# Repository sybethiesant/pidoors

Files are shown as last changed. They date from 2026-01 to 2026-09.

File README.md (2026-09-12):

# PiDoors - Open Source Access Control System






**Professional-grade physical access control powered by Raspberry Pi**

---

## Overview

PiDoors is a complete, industrial-grade access control system built on Raspberry Pi hardware. It provides enterprise-level security features while remaining affordable and open source. Designed for small businesses, makerspaces, office buildings, or anyone needing professional access control.

**Key Benefits:**
- **Cost-Effective**: 10x cheaper than commercial systems (~$100-150 per door vs $500-2000)
- **Secure**: TLS database encryption, bcrypt passwords, SQL injection protection, CSRF tokens
- **Open Source**: Full control over your security system
- **Modern Interface**: React SPA with TailwindCSS — fast, responsive single-page application
- **Offline Capable**: 24-hour local caching keeps doors working during network outages
- **Extensible**: Easy to customize and integrate

---

## Screenshots

| Dashboard | Doors |
|---|---|
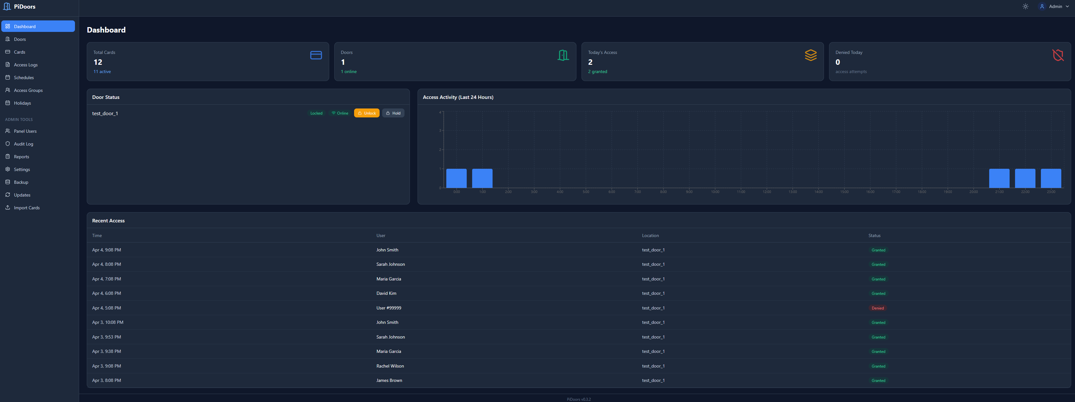
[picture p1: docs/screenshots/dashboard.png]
Dashboard
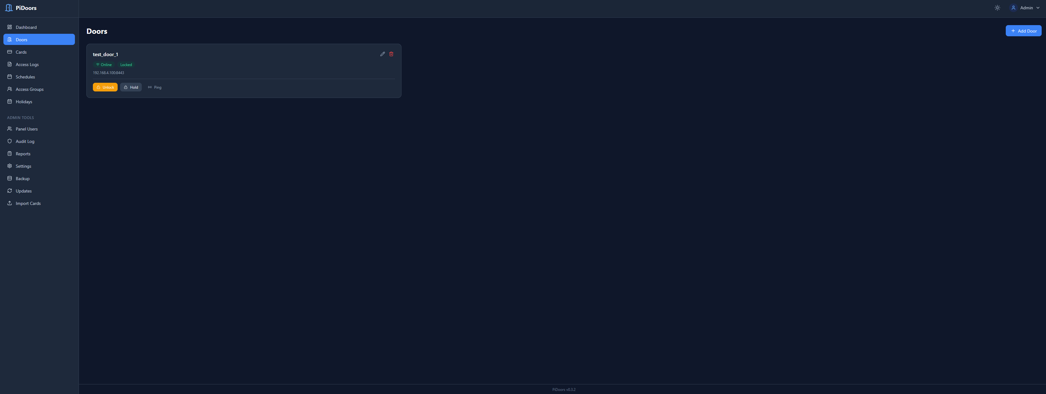
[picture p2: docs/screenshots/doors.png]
Doors
|  |  |

| Cards | Access Logs |
|---|---|
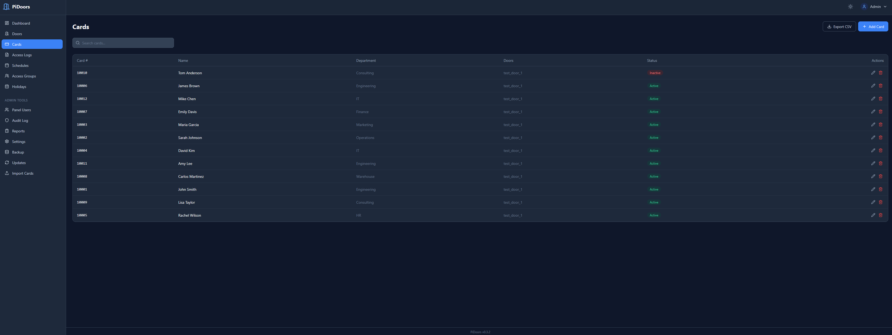
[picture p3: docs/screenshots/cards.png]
Cards
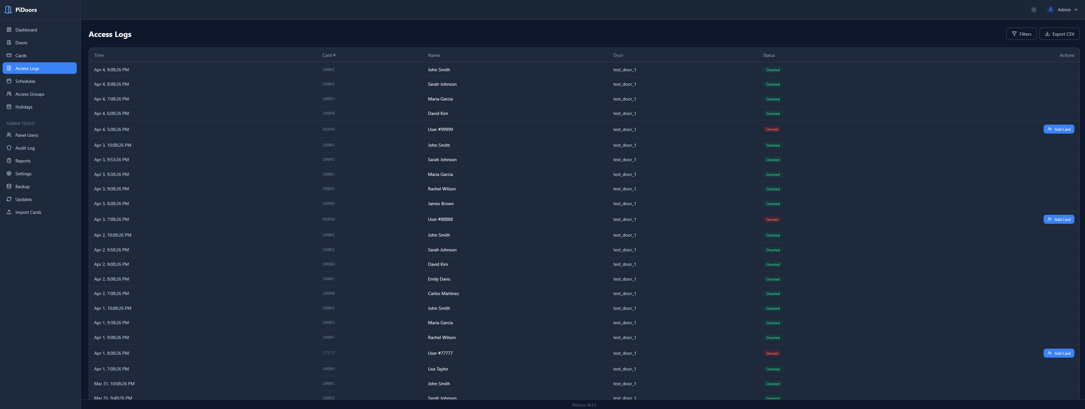
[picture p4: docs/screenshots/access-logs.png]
Access Logs
|  |  |

| Schedules | Access Groups |
|---|---|
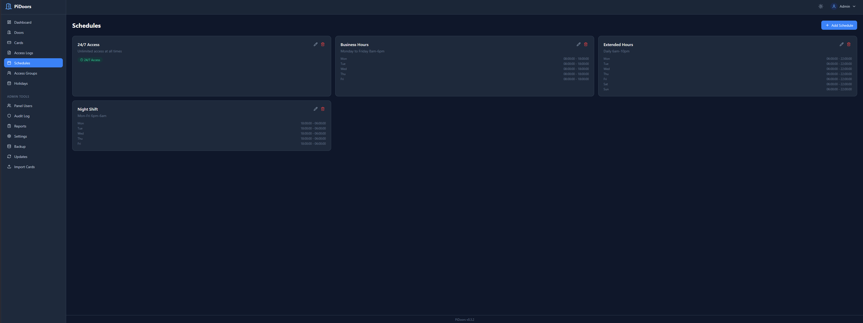
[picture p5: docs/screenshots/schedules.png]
Schedules
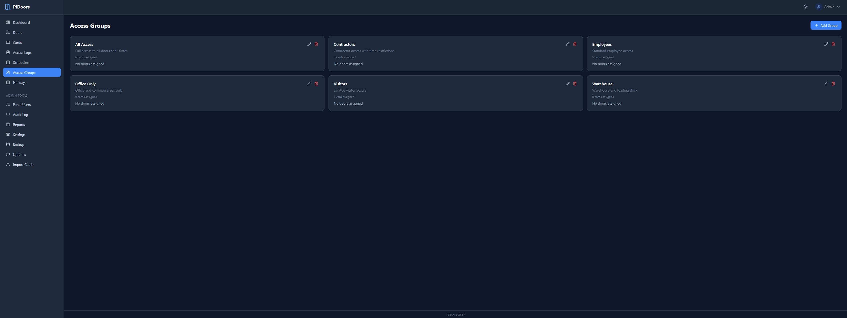
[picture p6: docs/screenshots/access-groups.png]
Access Groups
|  |  |

| Reports | Updates |
|---|---|
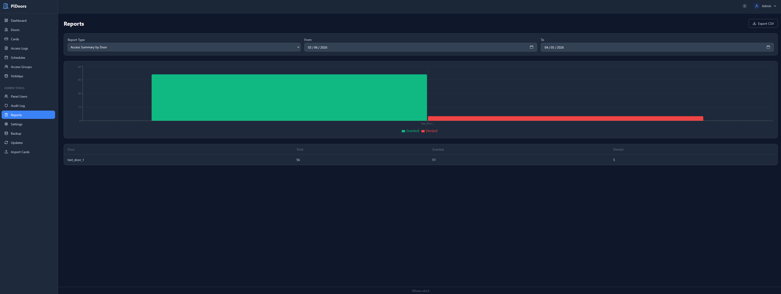
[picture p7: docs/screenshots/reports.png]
Reports
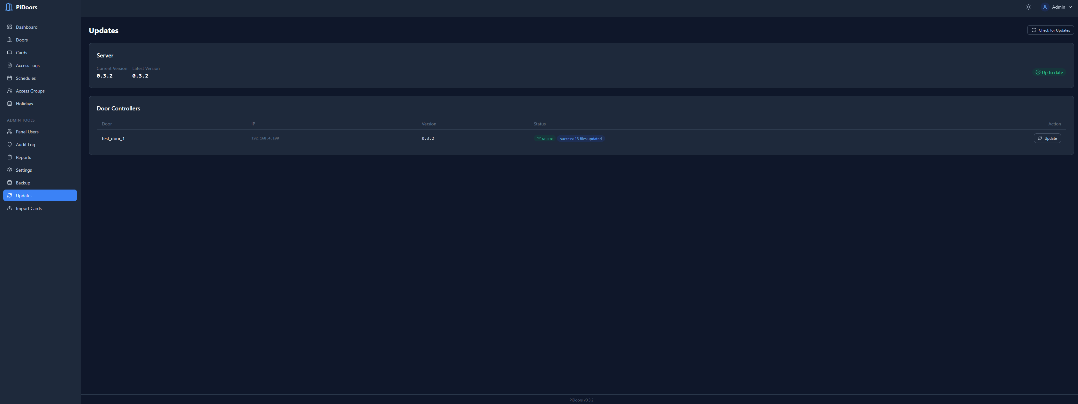
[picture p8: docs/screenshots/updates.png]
Updates
|  |  |

<details>
<summary>More screenshots</summary>

| Door Settings | Card Edit | Audit Log |
|---|---|---|
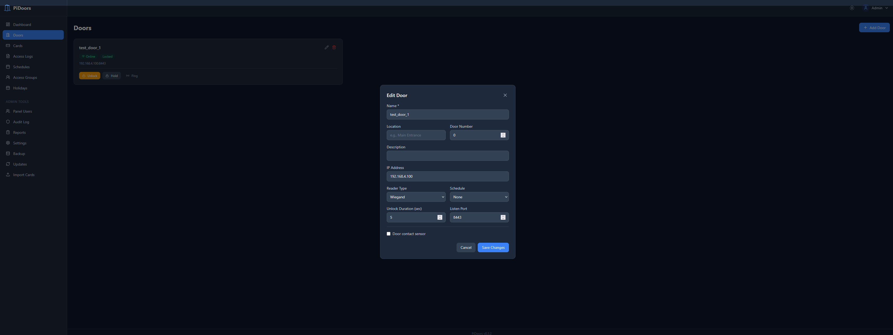
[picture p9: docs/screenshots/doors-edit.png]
Door Edit
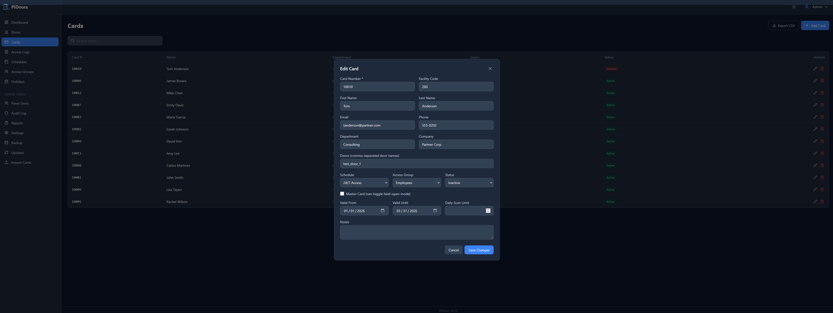
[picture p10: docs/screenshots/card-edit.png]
Card Edit
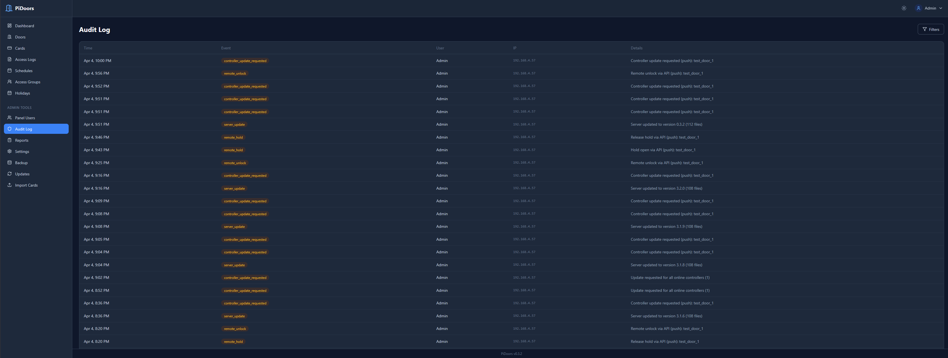
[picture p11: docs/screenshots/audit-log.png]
Audit Log
|  |  |  |

</details>

---

## Features

### Access Control
- **Multi-format Wiegand**: 26, 32, 34, 35, 36, 37, 48-bit with auto-detection
- **OSDP Readers**: RS-485 encrypted readers (planned — reader module included, not yet integrated)
- **NFC/RFID**: PN532 and MFRC522 support (planned — reader modules included, not yet integrated)
- Time-based access schedules
- Scheduled unlock — hold a door or gate open during a schedule's hours (e.g. a community gate open 6am–7pm)
- Access groups and permissions
- Holiday calendar support
- Card validity date ranges
- Persistent master cards (never expire for emergency access)
- **Master card toggle** in web UI — promote any card to master with a checkbox

### Gate Mode
- Toggle any door into **gate mode** for rolling/sliding gates with motor controllers
- 3 configurable inputs (open / stop / close physical buttons)
- 3 configurable outputs (open / stop / close relays to gate motor)
- Per-output hold duration, configurable polarity, configurable GPIO pins
- Triple-tap any button to enter hold-current-state
- Master card 3-scan = hold open (configurable)
- Stop interrupts the active output immediately
- Reverse direction commands automatically stop and reverse
- Web UI shows live gate state (idle/opening/closing/stopped/open/closed) and dedicated control buttons
- State persists across controller restarts
- Server-side pin conflict checker prevents double-assigning GPIO pins

### Reader LED
- Green / on while the door is unlocked or held open (schedule, master card or admin), red / off otherwise; a denied card blinks red
- Per-door green pin, optional red pin for bicolor readers, hi/lo polarity; defaults to the original GPIO 25 / GPIO 22 wiring
- Works on both doors and gates

### Management
- Modern React SPA with REST API backend
- Login by username or email
- Real-time dashboard with analytics
- Multi-user administration with extended profiles (name, department, company, etc.)
- Extended cardholder details (email, phone, department, employee ID, company, title)
- CSV bulk import/export with all cardholder fields (including master card flag)
- Comprehensive reporting
- Email notifications
- Complete audit trail
- Remote door control
- Instant offline detection via server-initiated polling (no stale heartbeat data)
- Door auto-registration from client heartbeat

### Updates
- One-click server updates from the web UI
- Remote controller updates via heartbeat signaling
- Pre-flight checks prevent partial updates
- Actionable error messages on failure
- Version tracking across all doors and server

### Reliability
- 24-hour offline operation
- Automatic failover
- Health monitoring
- Auto-reconnection
- Automated backups
- Service redundancy

### Security
- **TLS database encryption** — controller-to-server connections encrypted automatically
- Bcrypt password hashing (cost 12)
- PDO prepared statements (SQL injection proof)
- CSRF protection on all forms
- Secure session management
- Input validation and sanitization
- Security event logging
- Rate limiting on login

---

## Quick Start

### Prerequisites

- Raspberry Pi 3B+ or newer (Pi 4 recommended for server)
- Raspberry Pi OS (Debian-based, 64-bit recommended)
- Internet connection for initial setup
- Node.js and npm (installed automatically by `install.sh`)
- For door controllers: card reader hardware and relay module

### Automated Installation (Recommended)

```bash
# Download PiDoors
git clone https://github.com/sybethiesant/pidoors.git
cd pidoors

# Run installer as root
sudo ./install.sh
```

The installer presents three installation modes:

| Mode | Use Case |
|---|---|
| **1) Server** | Web interface + MariaDB database (run on your central Pi) |
| **2) Door Controller** | GPIO + card reader daemon (run on each door Pi) |
| **3) Full** | Both server and controller on one Pi (small deployments) |

#### What the installer does

1. Updates system packages
2. Installs dependencies (Nginx, PHP-FPM, MariaDB, Node.js, Python libraries)
3. Generates TLS certificates and enables encrypted database connections
4. Creates the `users` and `access` databases with all required tables
5. Imports the full database schema (base tables + migration extensions)
6. Deploys the PHP API to `/var/www/pidoors/`
7. Builds the React SPA and deploys to `/var/www/pidoors-ui/`
8. Configures Nginx to serve the SPA with `/api/*` routed to PHP-FPM
9. Prompts you to create an admin account (username, email + password)
10. Sets up log rotation and backup scripts

#### After installation

1. Open `https://your-pi-ip/` in a browser
2. Log in with the email (or username `Admin`) and password you set during install
3. Navigate to **Doors** to see your door controllers as they come online
4. Navigate to **Cards** to add access cards
5. Set up **Schedules** and **Access Groups** as needed

> **Installing a door controller on a separate Pi?** The server install prints a **controller enrollment token** at the end (also stored in `/var/www/pidoors/includes/config.php` as `enrollment_token`). Enter it when the door-controller install asks for it. It lets the controller obtain a CA-signed certificate so the server can push commands to it instantly; without it the controller still works, but commands fall back to database polling.

### Manual Installation

If you prefer to install manually or need to troubleshoot:

#### 1. Install system packages
```bash
sudo apt-get update && sudo apt-get install -y \
  nginx php-fpm php-mysql php-cli php-mbstring php-curl php-json \
  mariadb-server nodejs npm \
  python3 python3-pip python3-dev python3-venv git curl
```

#### 2. Create databases
```bash
sudo mysql_secure_installation

sudo mysql -u root -p <<'SQL'
CREATE DATABASE IF NOT EXISTS users;
CREATE DATABASE IF NOT EXISTS access;
CREATE USER IF NOT EXISTS 'pidoors'@'localhost' IDENTIFIED BY 'YOUR_PASSWORD';
CREATE USER IF NOT EXISTS 'pidoors'@'%' IDENTIFIED BY 'YOUR_PASSWORD';
GRANT ALL PRIVILEGES ON users.* TO 'pidoors'@'localhost';
GRANT ALL PRIVILEGES ON access.* TO 'pidoors'@'localhost';
GRANT ALL PRIVILEGES ON users.* TO 'pidoors'@'%';
GRANT ALL PRIVILEGES ON access.* TO 'pidoors'@'%';
FLUSH PRIVILEGES;
SQL
```

> **Note:** The `'pidoors'@'%'` user allows door controllers on other Pis to connect remotely. You also need to set `bind-address = 0.0.0.0` in `/etc/mysql/mariadb.conf.d/50-server.cnf` and restart MariaDB.

#### 3. Import schemas
```bash
# Create the users table and audit_logs table in the users database
sudo mysql -u root -p users <<'SQL'
CREATE TABLE IF NOT EXISTS `users` (
  `id` int(11) NOT NULL AUTO_INCREMENT,
  `user_name` varchar(100) NOT NULL,
  `user_email` varchar(255) NOT NULL,
  `user_pass` varchar(255) NOT NULL,
  `admin` tinyint(1) NOT NULL DEFAULT 0,
  `active` tinyint(1) NOT NULL DEFAULT 1,
  `created_at` datetime DEFAULT CURRENT_TIMESTAMP,
  `last_login` datetime DEFAULT NULL,
  PRIMARY KEY (`id`),
  UNIQUE KEY `user_email` (`user_email`)
) ENGINE=InnoDB DEFAULT CHARSET=utf8mb4;

CREATE TABLE IF NOT EXISTS `audit_logs` (
  `id` int(11) NOT NULL AUTO_INCREMENT,
  `event_type` varchar(50) NOT NULL,
  `user_id` int(11) DEFAULT NULL,
  `ip_address` varchar(45) DEFAULT NULL,
  `user_agent` varchar(255) DEFAULT NULL,
  `details` text,
  `created_at` datetime NOT NULL DEFAULT CURRENT_TIMESTAMP,
  PRIMARY KEY (`id`),
  KEY `event_type` (`event_type`),
  KEY `user_id` (`user_id`),
  KEY `created_at` (`created_at`)
) ENGINE=InnoDB DEFAULT CHARSET=utf8mb4;
SQL

# Import the access database schema and migration extensions
sudo mysql -u root -p access < database_migration.sql
```

The migration script creates all access tables, adds extended columns, and also switches to the `users` database to add profile columns. It is safe to re-run on existing installations.

#### 4. Create your admin user
```bash
# Generate a bcrypt hash for your password
HASH=$(php -r "echo password_hash('YOUR_PASSWORD', PASSWORD_BCRYPT);")

sudo mysql -u root -p users -e \
  "INSERT INTO users (user_name, user_email, user_pass, admin, active) \
   VALUES ('Admin', 'admin@example.com', '$HASH', 1, 1);"
```

#### 5. Deploy the PHP API
```bash
sudo mkdir -p /var/www/pidoors
sudo cp -r pidoorserv/* /var/www/pidoors/
sudo cp VERSION /var/www/pidoors/
sudo cp /var/www/pidoors/includes/config.php.example /var/www/pidoors/includes/config.php
sudo nano /var/www/pidoors/includes/config.php    # Set your database password and server IP
sudo chown -R www-data:www-data /var/www/pidoors
sudo chmod 640 /var/www/pidoors/includes/config.php
```

#### 6. Build and deploy the React SPA
```bash
sudo apt-get install -y nodejs npm
cd pidoors-ui
npm install && npm run build
sudo mkdir -p /var/www/pidoors-ui
sudo cp -r dist/* /var/www/pidoors-ui/
sudo chown -R www-data:www-data /var/www/pidoors-ui
cd ..
```

#### 7. Configure Nginx
```bash
# Detect your PHP version
PHP_VERSION=$(php -r "echo PHP_MAJOR_VERSION.'.'.PHP_MINOR_VERSION;")

# Install config with correct PHP socket path
sudo sed "s|php-fpm.sock|php${PHP_VERSION}-fpm.sock|g" \
  nginx/pidoors.conf > /etc/nginx/sites-available/pidoors
sudo ln -sf /etc/nginx/sites-available/pidoors /etc/nginx/sites-enabled/pidoors
sudo rm -f /etc/nginx/sites-enabled/default
sudo nginx -t && sudo systemctl reload nginx
```

See the [Installation Guide](pidoors/INSTALLATION_GUIDE.md) for additional details.

---

## System Architecture

```
                    REACT SPA (Browser)
     Dashboard | Cards | Doors | Logs | Reports | Settings
                          |
                     /api/* REST
                          |
     SERVER RASPBERRY PI
    +--------------------------+
    |  Nginx                   |
    |  ├─ /         → React   |
    |  └─ /api/*    → PHP-FPM |
    |  MariaDB (TLS)           |
    |  Backups & Logs          |
    +--------------------------+
          |                  |
     HTTPS Push         TLS/TCP DB
     (instant)          (sync/poll)
          |                  |
    +----------------+  +----------------+
    |  Door Pi #1    |  |  Door Pi #N    |
    |  Push Listener |  |  Push Listener |
    |  24hr Cache    |  |  24hr Cache    |
    |  Card Reader   |  |  Card Reader   |
    |  Electric Lock |  |  Electric Lock |
    +----------------+  +----------------+
```

**One server Pi** runs the React SPA, PHP API, and database.
**N door Pis** control individual access points with 24-hour local caching.
The server pushes commands instantly via HTTPS, with database polling as fallback.
The server pings controllers on each page load for instant status. Heartbeat runs every 5 minutes as a safety net.

---

## Hardware Requirements

### Server (1 per system)
| Component | Requirement |
|---|---|
| Board | Raspberry Pi 3B+ or newer (4GB RAM recommended) |
| Storage | 16GB+ microSD card |
| Network | Ethernet recommended |
| Power | Official Raspberry Pi power supply |

### Door Controller (1 per door)
| Component | Requirement |
|---|---|
| Board | Raspberry Pi Zero W or newer |
| Storage | 8GB+ microSD card |
| Reader | See supported readers below |
| Lock | 12V electric strike or magnetic lock |
| Relay | Relay module for lock control |
| Optional | Door sensor, REX button |

**Supported Card Readers:**
| Type | Interface | Notes |
|---|---|---|
| Wiegand (26/32/34/35/36/37/48-bit) | GPIO | Most common, auto-detection |
| Wiegand keypad (PIN codes) | GPIO | Burst mode or per-key (4/8-bit) mode — see *Wiegand Keypads (PIN Codes)* below |
| LCD display (HD44780) | I2C or GPIO | Optional status display at the door — see *LCD Display at the Door* below |
| OSDP v2 | RS-485 (UART) | Encrypted, requires USB-RS485 adapter — **planned, reader module not yet wired into the controller** |
| PN532 NFC | I2C or SPI | Mifare Classic, Ultralight, NTAG — **planned, reader module not yet wired into the controller** |
| MFRC522 NFC | SPI | Low-cost Mifare reader |

**Total cost per door: ~$100-150**

---

## Configuration

### Server Configuration

1. Copy the configuration template:
```bash
cp pidoorserv/includes/config.php.example pidoorserv/includes/config.php
```

2. Edit configuration:
```bash
nano pidoorserv/includes/config.php
```

3. Set your values:
```php
return [
    'sqladdr' => '127.0.0.1',
    'sqldb' => 'users',
    'sqldb2' => 'access',
    'sqluser' => 'pidoors',
    'sqlpass' => 'your_secure_password',
    'url' => 'https://your-pi-ip',
    // ... other settings
];
```

4. Secure the file:
```bash
chmod 640 pidoorserv/includes/config.php
```

### Door Controller Configuration

1. Copy the configuration template:
```bash
cp pidoors/conf/config.json.example pidoors/conf/config.json
```

2. Edit configuration:
```bash
nano pidoors/conf/config.json
```

3. Set your values (use your actual door name as the key):
```json
{
    "frontdoor": {
        "reader_type": "wiegand",
        "d0": 24,
        "d1": 23,
        "wiegand_format": "auto",
        "latch_gpio": 18,
        "open_delay": 5,
        "unlock_value": 1,
        "sqladdr": "SERVER_IP_ADDRESS",
        "sqluser": "pidoors",
        "sqlpass": "your_database_password",
        "sqldb": "access"
    }
}
```

---

## Wiring Guide

### Wiegand Reader to Raspberry Pi

**Important:** Most Wiegand readers output 5V logic signals, but Raspberry Pi GPIO pins are 3.3V only. A **bi-directional logic level shifter** (5V to 3.3V) is recommended on the DATA0 and DATA1 lines to protect the Pi's GPIO pins. Without one, the Pi may work initially but the GPIO pins can be damaged over time.

| Wiegand Reader | Level Shifter | Raspberry Pi |
|---|---|---|
| DATA0 (Green)  | HV1 → LV1 | GPIO 24 |
| DATA1 (White)  | HV2 → LV2 | GPIO 23 |
| GND (Black) | GND (shared)  | GND (Pin 6)  |
| 5V+ (Red) | HV | 5V (Pin 2) |
| — | LV | 3V3 (Pin 1)  |

### Lock Relay Control

| Relay Module | Raspberry Pi |
|---|---|
| IN | GPIO 18 |
| VCC | 5V (Pin 4) |
| GND | GND (Pin 14) |

Connect lock to relay NO/COM terminals with 12V power supply.

### Gate Mode Wiring (Optional)

For rolling/sliding gates with motor controllers, enable **Gate Mode** in the door edit page. Each gate has up to 3 inputs (physical buttons) and 3 outputs (relays to the gate motor). All inputs and outputs are optional — only enable the ones your hardware supports. GPIO pins are assigned in the web UI from the available pin list.

**Gate Outputs (relays to motor)** — typically wire each relay's NO/COM terminals to the corresponding input on your gate motor controller (open, stop, close terminals).

| Gate Output | Purpose |
|---|---|
| Open relay  | Held active for the configured duration to open the gate |
| Close relay | Held active for the configured duration to close the gate |
| Stop relay  | Optional — fires when stop is triggered, for motor controllers with a dedicated stop input |

**Gate Inputs (physical buttons or RF remote relays)** — wire the button/relay between the assigned GPIO pin and GND (default pull-up mode).

| Gate Input  | Purpose |
|---|---|
| Open button | Triggers the open output (3-tap = hold open) |
| Close button | Triggers the close output (3-tap = hold closed) |
| Stop button | Cuts the active output immediately (3-tap = hold at current position) |

**Voltage Warning:** Same as Wiegand readers — if your buttons or RF remote relays output 5V signals, use a level shifter to protect the Pi's 3.3V GPIO inputs. For dry-contact switches (relay closures to ground) no level shifter is needed.

In gate mode, the regular **Lock Relay** is unused — the gate's open/close outputs replace it. The "Unlock Duration" field in the door edit page is automatically hidden when gate mode is enabled. Each gate output has its own configurable hold duration.

### LED Feedback

The reader LED follows the state of the door, so members can see whether it is open right now:

| Door state | Green line | Red line (if wired) |
|---|---|---|
| Locked / idle | Off | On |
| Unlocked by a card, held open by a **schedule**, master card or admin, gate open cycle or gate held | On | Off |
| Card denied while locked | Off (single-line readers blink it on) | Blinks dark |
| Card denied while open | Blinks off | Blinks on (shows red) |

Configure it in the **Reader LED** section of the door edit page; changes take effect on the next config push, no restart needed.

- **LED pin (green / open)** — the line that is lit while the door is open. For readers with a single LED control input (most HID / Wiegand readers, where pulling the line low turns the LED green) this is the only pin you need; set **Active** to *Low* for those.
- **Red pin (optional)** — a second line for keypads with separate red and green inputs, or a two-wire bicolor LED. It is driven as the inverse of the green line.
- **Active** — high (3.3V) or low (GND) for both lines.

A door that has never had its LED configured uses the original wiring, GPIO 25 green and GPIO 22 red, active high, and that is what the form shows preselected. Untick **Reader LED** to stop driving those pins, which frees them for gate I/O, an LCD or a reader that needs them (the MFRC522 reset line, for example). All LED pins go through the same pin-conflict checks as everything else on the door.

### LCD Display at the Door

An optional character LCD (the common HD44780 type: 16x2, 20x4, etc.) can be attached to the controller to show what is happening at the door. Enable **LCD display** on the door edit page; the controller picks the change up on the next config push, no restart needed.

What it shows:
- **Idle**: the door name on line 1; `Ready`, `Held open`, `Gate held` or `LOCKDOWN` plus the time on line 2.
- **Access granted** with the cardholder's name, or **Access denied** with the reason, for 3 seconds.
- **Enter code** with one `*` per digit while a PIN is typed on a per-key keypad.

Two wiring types are supported. Pins are assigned in the web UI and checked against everything else on the door (reader, lock, sensor, gate I/O, status LED).

| Wiring | Config | Notes |
|---|---|---|
| **I2C backpack** (PCF8574 piggyback board, 4 wires) | Address (usually `0x27` or `0x3F`), bus (1) | Uses GPIO 2 (SDA) / GPIO 3 (SCL). Enable I2C once on the controller: `sudo raspi-config nonint do_i2c 0`, and make sure the service user can use the bus: `sudo usermod -aG i2c pidoors` (fresh installs do this for you). Find the address with `i2cdetect -y 1`. |
| **GPIO wired** (HD44780 in 4-bit mode) | RS, E, D4, D5, D6, D7, optional backlight pin | Tie RW to GND, D0–D3 unconnected, contrast pot on V0. Any free GPIO pins. |

Most 5V LCDs run happily with 3.3V logic on the data lines; power the panel from 5V. The display is best-effort: if it fails to initialise the controller logs `LCD setup failed` and carries on without it.

### Wiegand Keypads (PIN Codes)

A Wiegand keypad works with PiDoors today with no extra configuration. The controller does not distinguish a code typed on a keypad from a card presented to a reader: both arrive as a Wiegand frame, and a PIN is enrolled and managed exactly like a card. This also makes PiDoors usable for machine or equipment access (see the end of this section).

**What you need**

- Any keypad, or combined reader/keypad, with a Wiegand output. Both output modes work:
  - **Buffered / burst / "card format" mode**: the user types the digits and presses `#` (or waits for the keypad's timeout), and the keypad sends the whole code as **one** 26-bit (or 34/37-bit) frame. The controller decodes it like a card.
  - **Per-key mode** (4-bit or 8-bit "one frame per keypress"): the keypad sends each key as it is pressed. The controller collects the digits itself; `#` submits, `*` clears, and a pause of more than 5 seconds between keys discards a half-typed code. The digits are packed into the same 26-bit (or 34-bit for codes above 16,777,215) frame a burst-mode keypad would send, so a code enrolled on one kind of keypad matches on the other. Per-reader settings in `config.json`: `pin_timeout` (seconds, default 5) and `pin_max_length` (digits, default 10).
  - Most inexpensive keypads support both and default to per-key; the mode is a DIP switch or programming-code option in the keypad's manual (look for "Wiegand output format"). It no longer matters which one you pick.
- Wire DATA0 / DATA1 exactly like a card reader (see *Wiegand Reader to Raspberry Pi* above), including the 5V → 3.3V level shifter. The keypad's LED control line can go to GPIO 22 (see *LED Feedback*) so it turns green on a valid code.
- Nothing to change on the controller or in `config.json`. The frame is decoded by the same format registry (26/32/34/35/36/37/48-bit, parity checked).

**What does not work**

- **Card + PIN (two-factor).** The `pin_code` column on cards is stored, imported and exported, but the controller does not enforce it. A PIN is a standalone credential.
- **Non-Wiegand keypads**: matrix keypads on GPIO, I²C expanders such as the PCF8574, USB keypads. These would need a new reader module under `pidoors/readers/`. The `BaseReader` interface is there, but only the Wiegand reader is wired into the controller today; the OSDP and NFC modules are also not yet integrated.

**How a PIN becomes a credential**

- The keypad packs the digits into the frame's data bits. The controller validates parity, then splits the frame into *facility* + *user ID* by frame length (26-bit: 8 + 16 bits; 34-bit: 16 + 16; 37-bit: 16 + 19). A 6-digit code on a 26-bit keypad therefore usually shows up as a non-zero facility with a 5-digit user ID. That is expected: what matters is that the same code always produces the same pair.
- Code length is limited by the frame's data bits, not by a digit count: a 26-bit frame carries 24 data bits (codes up to 16,777,215, i.e. 8 digits), 34-bit carries 32. Some keypads impose their own maximum; check the manual.
- Leading zeros are not preserved: `000123` and `123` are the same credential.

**Enrolling a code**

1. Type the code on the keypad and press `#`.
2. The controller denies it as unknown, inserts it into the database as an **inactive** card, and logs the attempt (the controller must be able to reach the database for this; offline it just denies).
3. In the web UI open **Logs**, find the denied entry, and click **Set Up Card**. Give it a name, doors, group/schedule, and set it active.
4. Type the code again. Access is granted.

The same flow works for new cards, so a keypad or reader at any door doubles as an enrollment station. There is no need for a reader at the server.

**Machine / equipment access.** To gate a machine rather than a door, drive a latching relay or contactor that powers the machine from the lock relay output. Set the door's **Unlock Duration** to how long the machine should stay enabled after a valid code (up to the `max_unlock_duration` setting), use a master-card hold (3 scans) to keep it enabled indefinitely, or assign an **Unlock Schedule** to keep it powered during set hours.

### GPIO Pin Reference
```
    3V3  (1)  (2)  5V
  GPIO2  (3)  (4)  5V
  GPIO3  (5)  (6)  GND
  GPIO4  (7)  (8)  GPIO14
    GND  (9)  (10) GPIO15
 GPIO17 (11) (12) GPIO18    <- Relay (GPIO18)
 GPIO27 (13) (14) GND
 GPIO22 (15) (16) GPIO23    <- DATA1 (GPIO23)
    3V3 (17) (18) GPIO24    <- DATA0 (GPIO24)
 GPIO25 <- Green LED (legacy)
 GPIO22 <- Red LED (legacy)
```

Full wiring diagrams available in [Installation Guide](pidoors/INSTALLATION_GUIDE.md#wiring).

---

## Usage

### Adding a Card

**Via Web Interface:**
1. Navigate to **Cards** > **Add Card**
2. Enter card details (scan card at reader to get ID)
3. Assign access groups and schedules
4. Click **Add Card**

**Via a reader or keypad (auto-enrollment):**
1. Present the card (or type the PIN and press `#`) at any door. The attempt is denied and the credential is saved as an inactive card.
2. Open **Logs**, find the denied entry, click **Set Up Card**, fill in the details and set it active.

**Via CSV Import:**
```csv
card_id,user_id,firstname,lastname,email,department
12345678,EMP001,John,Smith,john@example.com,Engineering
87654321,EMP002,Jane,Doe,jane@example.com,Marketing
```

Upload at **Cards** > **Import CSV**. Optional columns: `email`, `phone`, `department`, `employee_id`, `company`, `title`, `notes`, `group_id`, `schedule_id`, `valid_from`, `valid_until`, `pin_code` (stored only; card + PIN is not enforced by the controller, see *Wiegand Keypads (PIN Codes)*).

### Creating Access Schedules

1. Go to **Schedules** > **Add Schedule**
2. Name the schedule (e.g., "Business Hours")
3. Add one or more **time windows**. Each window has a set of days (tap to toggle Mon–Sun) and a start/end time; a day can appear in as many windows as you need, and an end earlier than the start runs past midnight. For example, a gate that opens every day 11:30–13:10, Mon–Fri 16:45–18:30 and Sat–Sun 07:30–09:15 is three windows on one schedule.
4. Assign to cards (restricts when the card works) or to doors (see below)

### Access Groups

An access group carries a list of doors. A card assigned to a group is granted every door in the group's list **in addition to** the doors on the card itself, so you can manage door sets centrally and leave most cards' own door list empty. Notes:

- The group must list doors explicitly. A group with no doors selected grants nothing extra (it is just a label), and it never restricts a card's own doors.
- Schedules, validity dates, holidays and scan limits still come from the card.
- Controllers pick up group changes on their next cache sync (hourly, or immediately on a config push).

### Scheduled Unlock (Hold Open by Schedule)

To keep a door or gate open during set hours — a community gate open 6am–7pm, a lobby door unlocked during business hours — assign a schedule to the **door** in **Doors** > edit > **Unlock Schedule**.

- When the schedule window opens, the controller enters the held-open state (latch energized, or gate opened and held). When it closes, the door relocks (or the gate is released and closed).
- The controller evaluates the schedule every 15 seconds and acts on the transitions, so a master card or an admin can still release a hold mid-window; the schedule will not fight that release and re-applies on the next window start.
- A controller that reboots mid-window re-applies the hold. Clearing the door's schedule releases a hold the schedule applied.
- **Lockdown mode** and **access-denied holidays** override the schedule — a door that is locked down or closed for a holiday is never propped open.
- A schedule can have several windows a day (v0.4.9+); the door is held open during each one and relocks in the gaps between them.
- Overnight windows (e.g. 22:00 → 06:00) are supported. Master-card and admin holds placed *before* the window opens are left alone at window end.
- Card access is unaffected: outside the window the door works normally for authorized cards. Leave the door schedule at **None** for a door that should only ever open on a valid card.

### Monitoring Access

- **Dashboard**: Real-time statistics and charts
- **Access Logs**: Filter by date, door, user; export to CSV
- **Audit Log**: Track all administrative actions
- **Email Alerts**: Failed access attempts, door offline notifications

---

## Maintenance

### Automatic Backups
Backups run daily at 2 AM to `/var/backups/pidoors/` (database dumps plus the web root). Retention follows the **Backup retention (days)** value on the Settings page, default 30. The dump credentials live in the root-only file `/etc/pidoors/backup.cnf`.

### Manual Backup
```bash
sudo /usr/local/bin/pidoors-backup.sh
```

### Update PiDoors

**Via Web UI (Recommended):**
1. Go to **Updates** in the admin sidebar
2. Click **Check for Updates** to see the latest release
3. Click **Update Server** to update the web interface
4. Use the **Doors** page to push updates to door controllers

**Manual update:**
```bash
cd ~/pidoors
git pull
sudo cp -r pidoorserv/* /var/www/pidoors/
sudo systemctl restart nginx
sudo systemctl restart pidoors  # On door controllers
```

### Database Migrations

Both the in-app updater and `server-update.sh` apply `database_migration.sql` automatically through the root helper `/usr/local/sbin/pidoors-db-migrate` (v0.4.7+). If an update reports that the migration failed, fix the reported error and run:

```bash
sudo /usr/local/sbin/pidoors-db-migrate
```

If the helper is missing (installs made before v0.4.7 that have only ever updated through the web UI), run `sudo bash server-update.sh` once from the extracted release; it installs the helper and applies any missed migrations.

To run the migration by hand instead:

```bash
# Backup first
mysqldump -u pidoors -p access > backup_access_$(date +%Y%m%d).sql
mysqldump -u pidoors -p users > backup_users_$(date +%Y%m%d).sql

# Run migration (safe to re-run, uses IF NOT EXISTS checks)
mysql -u root -p access < database_migration.sql
```

The migration script handles both the `access` and `users` databases automatically.

**v2.2.1 Migration (Required if upgrading from v2.2 or earlier):**

This migration converts door assignments from space-separated to comma-separated format:

```bash
python3 migrations/migrate_doors_format.py --dry-run   # Preview
python3 migrations/migrate_doors_format.py              # Apply
```

### View Logs
```bash
# Door controller logs
sudo journalctl -u pidoors -f

# Web server logs
sudo tail -f /var/log/nginx/pidoors_error.log
```

---

## Security

### Security Features
- TLS encryption for all database connections (auto-configured during install)
- Bcrypt password hashing with automatic MD5 upgrade
- PDO prepared statements (no SQL injection)
- CSRF token protection on all forms
- Secure session handling with timeout
- Comprehensive input validation
- Complete audit logging
- Login rate limiting (5 attempts, 15-minute lockout)

### Reporting Vulnerabilities
Please report security issues to the repository owner directly, not via public issues.

---

## File Structure

```
pidoors/
├── pidoorserv/           # PHP API backend
│   ├── api.php           # Unified REST API router
│   ├── includes/         # Core PHP includes
│   │   ├── config.php.example
│   │   ├── security.php
│   │   ├── header.php
│   │   ├── push.php      # Push communication & status polling
│   │   ├── notifications.php
│   │   └── smtp.php      # Lightweight SMTP sender
│   ├── cron/             # Scheduled tasks (notifications)
│   ├── users/            # User management
│   ├── database/         # Database connection
│   ├── css/              # Stylesheets (legacy)
│   └── js/               # JavaScript (legacy)
├── pidoors-ui/           # React SPA frontend
│   ├── src/
│   │   ├── pages/        # Dashboard, Cards, Doors, Settings, etc.
│   │   ├── components/   # Shared UI components
│   │   ├── contexts/     # Auth context
│   │   ├── api/          # REST API client
│   │   └── types/        # TypeScript type definitions
│   ├── package.json
│   └── vite.config.ts
├── pidoors/              # Door controller
│   ├── pidoors.py        # Main daemon
│   ├── pidoors.service   # Systemd service
│   ├── pidoors-update.sh # Self-update script (runs as root via sudo)
│   ├── readers/          # Card reader modules
│   │   ├── base.py       # Abstract base class
│   │   ├── wiegand.py    # Wiegand GPIO reader
│   │   ├── osdp.py       # OSDP RS-485 reader
│   │   ├── nfc_pn532.py  # PN532 NFC reader
│   │   └── nfc_mfrc522.py # MFRC522 NFC reader
│   ├── formats/          # Card format definitions
│   │   └── wiegand_formats.py
│   └── conf/             # Configuration
│       └── config.json.example
├── nginx/                # Nginx configuration
│   └── pidoors.conf
├── docker/               # Docker dev/test environment
│   ├── docker-compose.yml
│   ├── Dockerfile.server
│   ├── Dockerfile.door
│   ├── server-entrypoint.sh
│   ├── door-entrypoint.sh
│   ├── deploy.sh         # Deploy to remote Docker host
│   └── mock_gpio.py      # Mock GPIO for containerized door
├── VERSION               # Current version number
├── install.sh            # Installation script
├── server-update.sh      # Server self-update script
├── database_migration.sql
└── README.md
```

---

## Documentation

| Document | Description |
|---|---|
| [Installation Guide](pidoors/INSTALLATION_GUIDE.md) | Complete beginner-friendly setup |

---

## Contributing

Contributions welcome! Please:

1. Fork the repository
2. Create a feature branch (`git checkout -b feature/amazing-feature`)
3. Commit your changes (`git commit -m 'Add amazing feature'`)
4. Push to the branch (`git push origin feature/amazing-feature`)
5. Open a Pull Request

**Requirements:**
- Test on actual Raspberry Pi hardware
- Verify database migrations work
- Check security implications
- Update documentation

---

## Roadmap

**Current Version: 0.4.11** - Pre-release

**Future Enhancements** (community contributions welcome):
- Mobile app (iOS/Android)
- Bluetooth Low Energy (BLE) readers
- Biometric integration (fingerprint, face)
- Cloud backup integration
- Multi-site management dashboard

---

## Changelog

> **Note:** Version numbering was reset from 3.x to 0.x in April 2026. The project had rapidly iterated from v1.0 to v3.2 during initial development. The 0.x series reflects pre-release status as the system matures toward a proper v1.0.0 release.

### Version 0.4.11 (September 2026)
- **Reader LED stays green for as long as the door is open — fixes #8.** The configurable status LED (any GPIO pin) only pulsed for two seconds on a granted scan; during a scheduled unlock, a master-card or admin hold, or even the rest of a normal five-second unlock it went dark, although the feature list had claimed it lit "during hold states" since 0.3.3. Only the hardcoded GPIO 25 line did that. The LED now follows the door: on / green while the latch is energised or the door or gate is held, off / red otherwise, and scan animations settle back to the real state instead of switching a held-open LED off.
  - **Denied card while the door is open blinks red** (single-line LED blinks off) so a refused card is visible against the steady green. At idle a bicolor pair still blinks its red dark and a single-line LED blinks on.
  - **The old hardcoded GPIO 22 / 25 LEDs are now the default of the same configurable feature** instead of a separate always-on code path. The door edit page's **Reader LED** section has a green pin, an optional red pin and the polarity, preselected to GPIO 25 / GPIO 22 for doors that never configured an LED. Those pins finally take part in the pin-conflict checker, so a gate relay, LCD line or reader that needs GPIO 22 or 25 is reported instead of being silently fought by the LED code; untick **Reader LED** or move it to free them.
  - Existing single-pin status LED configs carry over as the green line with no red line. Doors that had such a config *and* relied on the hardcoded pair being driven as well should add GPIO 22 as the red pin, or move the green line to GPIO 25.
  - Gate mode: the LED goes green for every open cycle and while the gate is held, not only for card-triggered opens.

### Version 0.4.10 (September 2026)
- **Schedule, holiday, card, group, door and settings changes reach online doors immediately — fixes #7.** Controllers cache this data and only re-read it from the database once an hour, and the server only pushed a reload for gate/LED/LCD config changes. Assigning an **Unlock Schedule** to a door, or editing the schedule's hours, therefore did nothing until the next hourly sync (or a controller restart). The API now pushes a cache sync to every reachable controller after any such change, in parallel and after the HTTP response is sent, so the UI is never held up by a slow door. Doors that are offline still catch up on their next sync.
  - The controller re-evaluates its unlock schedule right after each sync, so a window that is already open is applied within a second instead of at the next 15 s tick. Concurrent syncs (hourly vs. pushed) are serialized.
  - Card swipes were never affected while online: the controller checks the database live for those and only uses its cache when the server is unreachable.

### Version 0.4.9 (September 2026)
- **Schedules can have more than one time window per day — fixes #6.** A schedule used to hold a single start/end per weekday, so "open 11:30–13:10 and again 19:25–21:10 every day, plus 16:45–18:30 on weekdays" could not be expressed. Schedules are now a list of windows, each with its own set of days and start/end time, with no limit on how many windows share a day. This applies to both card access schedules and door **Unlock Schedules**.
  - New `schedule_windows` table. The migration seeds it from the existing per-day columns, so current schedules carry over unchanged.
  - The legacy per-day columns are kept and always mirror each day's *first* window, so a controller still on an older release keeps enforcing a reduced version of the schedule until it is updated. Update controllers to 0.4.9 to get every window.
  - Schedules page redesigned around the window list (day toggles + start/end per row). Older API clients that still send the per-day fields keep working.

### Version 0.4.8 (September 2026)
- **`server-update.sh` failed at "Release archive missing pidoorserv/ directory".** Its temp directory is named `pidoors-server-update-…`, and the search for the extracted `pidoors-*` folder matched the temp directory itself. The CLI updater had been broken since that temp-dir naming was introduced; the in-app updater was unaffected. This matters now because v0.4.7 tells existing installs to run it once. Also: the migration helper no longer echoes the migration's placeholder `SELECT 1` rows.

### Version 0.4.7 (September 2026)
- **Database migrations now actually run on upgrades.** Since the v0.4.0 hardening the app DB user has had no CREATE/ALTER, so the migration step in both the in-app updater and `server-update.sh` failed on its first statement and was reported as a *warning*. Every schema change shipped since then was silently skipped on upgraded installs (fresh installs were fine). v0.4.6 was the first release to add a column (`lcd_config`), which made this visible: saving a door's LCD config failed with an unknown-column error.
  - New root helper `/usr/local/sbin/pidoors-db-migrate` runs the deployed migration as a dedicated `pidoors_migrate` DB user (DDL on the two PiDoors databases only, credentials in root-only `/etc/pidoors/migrate.cnf`). The web updater calls it via sudoers, the same way as the nginx helper.
  - A failed migration is now an **error** in the UI and a non-zero exit from `server-update.sh`, with the command to fix it.
  - **Existing installs:** run `sudo bash server-update.sh` once (from the extracted release or a clone). It installs the helper and the DB user, asking for the MariaDB root password only if root needs one, and applies any missed migrations. After that, in-app updates handle schema changes on their own.

### Version 0.4.6 (September 2026)
- **Per-key Wiegand keypads now work.** Keypads in 4-bit or 8-bit "one frame per keypress" mode were ignored (`Unsupported Wiegand format`). The controller now collects the keys itself (`#` submits, `*` clears, 5 s inter-key timeout) and packs the digits into the same 26/34-bit frame a burst-mode keypad sends, so the same code enrolls and matches on either kind. Per-reader `pin_timeout` / `pin_max_length` in `config.json`. Closes the remaining question on issue #4.
- **LCD display at the door.** Optional HD44780 character LCD, either on a PCF8574 I2C backpack or wired to GPIO in 4-bit mode, configured per door in the web UI with pin-conflict checking. Shows door name and hold/lockdown state at idle, granted/denied with name or reason, and PIN entry progress. New `lcd_config` column on `doors`, new `pidoors/lcd.py` on the controller. See *LCD Display at the Door*.

### Version 0.4.5 (September 2026)
**Audit fixes.** A sweep of the controller, API, SPA and installer for features that were exposed but not wired up. Everything below was broken or inert before this release.

Controller
- **Access groups now grant access.** The controller never read `access_groups`, so a group's door list was a label. Cards whose group lists the door are now included in the door's cache and pass the online check. Groups must name doors explicitly; an empty group grants nothing (conservative on upgrade). See *Access Groups* under Usage.
- **Schedules starting at 00:00 denied access on the offline path** — the cached check used falsiness and PyMySQL returns midnight as `timedelta(0)`. Now `is None`, matching the DB path.
- **Recurring holidays with a past date never reached the offline cache** (`date >= CURDATE()` dropped them). Recurring rows are always synced.
- **Global settings were dropped from the cache file** because it was saved before they were attached. Saved after.
- **Lockdown mode is read on the fast command poll**, so it takes effect within seconds instead of on the hourly sync.
- Docstring no longer claims OSDP/NFC support; the reader-type dropdown marks those options as planned and disabled.

Server / web UI
- **Controller certificate enrollment could never succeed.** `/api/certs/sign` refused unless `enrollment_token` was set in config.php, and nothing ever set or sent it — every controller fell back to a self-signed cert the server's CA pin then rejected, so push commands silently degraded to polling. The server install now generates the token (printed in the summary), the door install prompts for it, and all three signing callers send it. Existing installs: set `enrollment_token` in config.php, add it to the controller's `config.json`, and re-run `pidoors-update.sh` to re-sign.
- **In-app server update now verifies the published `.sha256`** before extracting and no longer falls back to the GitHub source archive (which skipped verification and contained no built SPA). Matches `server-update.sh`.
- **"Send Test Email" always failed** — it called a function that did not exist. Uses the SMTP sender.
- **Cards created in the UI could not be edited or deleted** until first scanned (the API keys on `card_id`, which is NULL until then). They can now be addressed by primary key.
- **Creating a door dropped its gate, status-LED and lockdown settings** — only the edit path saved them. The create path persists and validates them too; a door named `all` is rejected (it collides with the update-all route).
- **Security settings were inert.** Login lockout attempts/duration and password rules edited on the Settings page are now applied (they were read from config.php only).
- Notification emails link to the SPA routes instead of the retired `.php` pages.
- Schedules, Access Groups and Holidays are hidden from non-admins instead of loading and failing with 403.
- Update page compares versions numerically (string compare broke past `0.4.9`).

Installer
- **Automatic backup is actually scheduled** (daily 02:00). It was installed but never added to cron. Retention now follows the Settings page value, and the DB password moved from a command-line argument to a root-only credentials file.
- The `nginx/` template is copied into the web root so the nginx upgrade helper has a source after a fresh install.

Not changed (known, documented): `pin_code` and anti-passback columns are stored but unused; several Settings keys (`maintenance_mode`, `log_retention_days`, `cache_duration`, `default_*`) are saved but read by nothing; legacy PHP pages are still shipped though unreachable behind the SPA nginx config.

### Version 0.4.4 (September 2026)
**Scheduled unlock (hold open by schedule) — fixes #5.** The **Schedule** dropdown on the door edit page has existed since the schedules feature landed, but the controller never read `doors.schedule_id` — the field was saved and then ignored, so "hold the gate open 6am–7pm" silently did nothing. The controller now runs an unlock-schedule thread that holds the door (or opens and holds the gate) when the assigned schedule's window opens and releases it when the window closes. It is edge-triggered, so master-card / admin releases mid-window are respected; it re-applies after a reboot mid-window; and lockdown mode or an access-denied holiday overrides it. The field is now labeled **Unlock Schedule** in both UIs with the behavior spelled out. See *Scheduled Unlock* under Usage.

**Dependency security updates** — React SPA toolchain, `npm audit`: 0 vulnerabilities. Both are build-time (dev) dependencies; neither ships in the deployed bundle or is reachable from the web UI.
- `browserslist` 4.28.2 → 4.28.9 — uncaught crash / prototype write via untrusted `browserslist-stats.json` custom stats in `normalizeStats` ([GHSA-73wf-gq98-2v4g](https://github.com/advisories/GHSA-73wf-gq98-2v4g), CVE-2026-73088).
- `postcss-selector-parser` 6.1.2 → 6.1.4 — denial of service through uncontrolled AST recursion ([GHSA-w9m9-85wc-3x92](https://github.com/advisories/GHSA-w9m9-85wc-3x92), CVE-2026-9358).

### Version 0.4.3 (August 2026)
**Dependency security updates** — clears every open advisory in the React SPA toolchain (`npm audit`: 0 vulnerabilities). No application code changed; the pre-built SPA bundle was rebuilt against the patched dependencies.
- `postcss` 8.5.15 → 8.5.26 — fixes a path traversal in source-map auto-loading, where a crafted `sourceMappingURL` comment could disclose arbitrary `.map` files ([GHSA-r28c-9q8g-f849](https://github.com/advisories/GHSA-r28c-9q8g-f849)).
- `react-router` / `react-router-dom` 6.30.4 → 7.18.2 — the open redirect leading to XSS ([GHSA-jjmj-jmhj-qwj2](https://github.com/advisories/GHSA-jjmj-jmhj-qwj2)) has no patch on the 6.x line, so this required the 6 → 7 major upgrade. That also picks up arbitrary constructor injection via `deserializeErrors()` in SSR hydration ([GHSA-337j-9hxr-rhxg](https://github.com/advisories/GHSA-337j-9hxr-rhxg)) and an open redirect via backslash in `<Link>` / `useNavigate` ([GHSA-wrjc-x8rr-h8h6](https://github.com/advisories/GHSA-wrjc-x8rr-h8h6)).

The router major needed no source changes: the UI uses only `BrowserRouter`, `Routes`, `Route`, `Navigate`, `Outlet`, `Link`, `NavLink`, `useSearchParams` and `useNavigate` — all unchanged in v7 — and has no data-router loaders/actions, `<Form>`, or splat-relative links.

### Version 0.4.2 (June 2026)
**Installer fix.** A fresh `sudo ./install.sh` failed on every run under the `set -euo pipefail` hardening added in v0.4.0: the `prompt` / `prompt_secret` helpers referenced uninitialized variables — `local value` (tested by `while [ -z "$value" ]`) and an optional positional `default="$3"` — which `set -u` (nounset) treats as a fatal "unbound variable" error, aborting the install at the first password/email prompt. Initialized both (`local value=""`, `default="${3:-}"`) so the installer completes. No application code or dependency changes; the secured v0.4.1 SPA bundle is unchanged.

### Version 0.4.1 (June 2026)
**Dependency security updates** — patched every known npm advisory in the React SPA toolchain (`npm audit`: 0 vulnerabilities). No application code changed; the pre-built SPA bundle was rebuilt against the patched dependencies.
- `react-router` / `react-router-dom` 6.30.3 → 6.30.4 — fixes an open redirect via protocol-relative URL reinterpretation ([GHSA-2j2x-hqr9-3h42](https://github.com/advisories/GHSA-2j2x-hqr9-3h42)).
- `postcss` 8.5.9 → 8.5.15 — fixes XSS via an unescaped `</style>` in stringify output ([GHSA-qx2v-qp2m-jg93](https://github.com/advisories/GHSA-qx2v-qp2m-jg93)).
- `vite` → 6.4.3 — fixes a `server.fs.deny` bypass and an NTLMv2 hash-disclosure issue in the dev server on Windows ([GHSA-fx2h-pf6j-xcff](https://github.com/advisories/GHSA-fx2h-pf6j-xcff)).
- `@babel/core` → 7.29.7 — fixes arbitrary file read via a `sourceMappingURL` comment ([GHSA-4x5r-pxfx-6jf8](https://github.com/advisories/GHSA-4x5r-pxfx-6jf8)).

### Version 0.4.0 (June 2026)
**Security and reliability hardening.**

Controller:
- **Fail closed on the DB link** — a provisioned TLS CA is now required; removed the plaintext-HTTP CA bootstrap and the silent fallback to unencrypted MySQL.
- **Consistent `card_id` width** across the registry and legacy Wiegand decoders.
- **Gate IO teardown** before re-registering (no more `RuntimeError` on re-sync) and when gate mode is disabled.
- **Heartbeat-aware** — reads `heartbeat_interval` from settings so healthy doors aren't flagged offline; re-seeds reader runtime state on `SIGHUP`; poll loop reads zone config fresh.
- **Master-card / lockdown safety** — bounds master-card fail-open with a local staleness window, enforces `lockdown_mode` (deny non-master cards, offline-safe), and handles overnight schedule wrap.
- **Atomic cache/master-card writes**; online grants logged to the offline counter; offline cache sync now matches door lists containing spaces.

Server:
- **`push` fails closed when the CA is missing** (previously leaked the per-door unlock key).
- **Certificate signing requires a separate enrollment token**; legacy MD5 logins rejected.
- **`card_id` is never invented server-side**; CSV import preserves it; PINs redacted from list/export responses.
- Offline-detection threshold matched to the controller heartbeat.

Installer / updaters / docker:
- **Release tarball checksums verified before deploy**; server cert verified during controller enrollment (no `CERT_NONE`, no HTTP CA fallback).
- **No hardcoded default admin/DB passwords** — env required, fails if unset; scoped DB grants; safe SQL quoting; example user seeded inactive.
- Fixed the `php-json` install abort; `set -euo pipefail`; corrected `DOOR_SRC` ordering.
- Pinned docker base images, added healthchecks and ordered startup.
- Completed controller reader requirements; tightened CSP (dropped `script-src 'unsafe-inline'`); removed the duplicate database migration.

### Version 0.3.10 (April 2026)
- **Legacy LED fix for gate mode** — GPIO 22/25 legacy LEDs now toggle correctly in gate mode. Previously gate access routed through `gate_command()`, which never touched the hardcoded LED pins, so the keypad LED stayed red on valid access. `_set_legacy_leds()` now fires for both door and gate paths (green during the gate open cycle, back to red when done).
- **LEDs decoupled from the lock relay check** — legacy LEDs work even when `latch_gpio` isn't set (e.g. gate mode, where the lock relay is replaced by gate outputs).
- **Docs** — added an LED Feedback section to the README wiring guide covering both the legacy hardcoded LEDs and the configurable Status LED.

### Version 0.3.9 (April 2026)
- **React 18 → 19** — major framework migration, built and bundled (users get it automatically via the pre-built SPA tarball, no npm required)
- **Vite 5 → 6** — build toolchain upgrade
- **@vitejs/plugin-react 4 → 5** — React 19 compatibility
- **@tanstack/react-query 5.60 → 5.99** — performance and bug fix patches
- **Python requirements safety net** — new `requirements.txt` in the controller directory. `pidoors-update.sh` now runs `pip install -r requirements.txt` on every update so future new Python dependencies install automatically. `install.sh` also uses it.
- **Zero vulnerabilities** — npm audit clean after the migration

### Version 0.3.8 (April 2026)
- **Gate auto-close** — gates can now auto-close after opening, with a configurable delay (1–3600 seconds). Mandatory clearance sensor input ensures the gate won't auto-close on a person, vehicle, or obstruction.
- **Clearance sensor input** — new optional 4th gate input for beam-break, IR, or laser clearance sensors at the gate opening. Configurable polarity and "active means clear/blocked" logic.
- **Auto-close safety** — UI greys out the auto-close toggle until a clearance sensor is configured. The API rejects auto-close enable requests without a sensor. The controller refuses to fire auto-close if the sensor is missing or the path is blocked.
- **Auto-close interruption** — any manual command (open/close/stop/hold) cancels a pending auto-close timer. The clearance sensor breaking restarts the timer when clear again.
- **Dashboard gate controls** — the dashboard's door status panel now mirrors the doors page for gates: gate state badge, held badge, and Open/Stop/Close/Hold/Release buttons.
- **Session timeout fix** — `session_timeout = 0` (unlimited) now actually works. Sessions are stored in a custom save path to bypass Debian's `phpsessionclean` cron, which would otherwise delete idle sessions after 24 minutes regardless of the app-level setting.

### Version 0.3.7 (April 2026)
- **Gate command errors are actionable** — instead of the generic "Could not reach the gate controller" message, the web UI now shows specific reasons: "Gate is held. Release the hold first.", "No output pin is configured for this direction.", "Gate is already opening.", etc.
- **Gate state syncs immediately** — server-side status polling now reads `gate_state` and `gate_held` from the controller's `/ping` response, so the `Held` badge and current state update in near-real-time on the doors page
- **Gate commands update DB immediately** — clicking open/close/stop/hold/release reflects on the UI on the next poll (no more waiting for the 5-minute heartbeat)
- **Fix**: `push_to_controller` failure now correctly distinguished from "controller reached but command refused"

### Version 0.3.6 (April 2026)
- **Fix**: `index.html` no longer cached by browsers — nginx now sends `Cache-Control: no-cache` for the SPA entry point so users don't see stale UI after an update. Hashed JS/CSS assets still cache for a year.
- **Fix**: Web UI server updates now also upgrade the nginx config if it's changed (via a new root-owned helper script + sudoers entry for www-data). This deploys nginx changes like the cache-control fix without requiring shell access.
- **Fix**: Python `SyntaxError` in the controller's rename handler (nested `global zone` declaration) that bricked the service after updating to 0.3.5.

### Version 0.3.5 (April 2026)
- **Fix**: Door rename could corrupt `config.json` when the controller's in-memory `zone` variable fell out of sync with the on-disk config after a failed restart
- **Fix**: Rename handler updates the in-memory `zone` immediately so subsequent pushes work even if the service restart fails
- **Fix**: Sudoers now allows `systemctl restart pidoors` so rename can actually restart the service
- **Fix**: Rename refuses to proceed if the old zone key is missing from config.json (prevents creating empty broken entries)
- **Fix**: Same-name renames are a no-op
- **Fix**: Update script guards against double self-update in the same chain
- **Fix**: Update script reads zone from `zone.json` (source of truth) and refuses to create a phantom empty zone entry if the zone is missing

### Version 0.3.4 (April 2026)
- Pin selector dropdowns show all GPIO pins but disable ones already in use — both within the form (other gate I/O, status LED, sensor) and by reserved hardware features (reader, lock relay)
- Disabled options labeled clearly as `GPIO X (in use)` or `GPIO X (Wiegand DATA0)`
- Hide `Unlock Duration` field when gate mode is enabled
- Documentation: gate mode and status LED sections added to README and INSTALLATION_GUIDE

### Version 0.3.3 (April 2026)
- **Gate mode** — toggle on the door edit page to convert a door into a gate with open/close/stop inputs and outputs
- **Configurable gate I/O** — each input/output is optional with assignable GPIO pin, hi/lo polarity, and (for outputs) hold duration
- **Triple-tap hold** — physical open/close/stop buttons enter hold-current-state when triple-tapped within the configured window
- **Gate state reporting** — controller reports current gate state (idle/opening/closing/stopped/open/closed/held) to the web UI
- **Gate web UI** — dedicated open/close/stop/hold/release buttons on the doors page when in gate mode, with status badge
- **Status LED feature** — universal configurable LED that lights up on access events and during hold states (works on doors and gates)
- **Pin conflict checker** — server-side endpoint validates GPIO pin assignments don't conflict with reader, sensor, or other features
- **Master scan settings** — configurable master scans to hold open / release hold (defaults: 3 / 1)
- **Push timeout fix** — increased default push timeout from 3s to 5s to accommodate Pi Zero TLS handshake delays
- **Door rename push** — when renaming a door, server pushes the new name to the controller, which updates its config and restarts

### Version 0.3.2 (April 2026)
- **Door rename protection** — doors must be online to rename; server pushes the name change to the controller, which updates its config and restarts
- **Reliable controller self-updates** — update script detaches from the service cgroup before stopping the service; temp files use `/var/cache/` to survive PrivateTmp
- **Self-update compatibility** — patches older release scripts during self-update with cgroup detach, venv python, and temp dir fixes for seamless upgrades from any prior version
- **Version transition** — update system handles the 3.x → 0.x renumbering so existing installations update seamlessly
- **Heartbeat fix** — `door_sensor_open` missing global declaration broke heartbeat entirely; doors never auto-registered or showed online
- **MariaDB TLS** — fixed three issues preventing TLS on fresh installs: grep matched commented-out defaults, wrong config section header on newer MariaDB, server cert missing SAN IP
- **CA cert signing** — fixed serial file permissions and empty tempfile issues that broke the signing API
- **Update script** — uses venv Python for pymysql, adds curl timeouts, re-signs listener cert on every update
- **Installer improvements** — socket auth detection, SSL permissions always applied, menu formatting fixed
- **Pre-built React SPA** included in release tarballs (no Node.js needed for server updates)

### Earlier History (January — March 2026)
- **v3.0**: React SPA frontend rewrite, REST API, push-based instant controller communication via HTTPS
- **v2.6**: TLS database encryption, email notifications, self-healing TLS connections
- **v2.5**: Version tracking, server and controller self-update system, remote door unlock
- **v2.4**: Master card web UI, GPIO fix for Debian Bookworm (rpi-lgpio), automated installer
- **v2.3**: Login by username, extended user/cardholder profiles, CSV import
- **v2.2**: Multi-reader support (Wiegand/OSDP/NFC), security hardening, Bootstrap modals
- **v2.0**: Security overhaul, 24-hour offline caching, time-based schedules
- **v1.0**: Initial release — basic Wiegand 26-bit support, simple web interface
- Email notifications
- Automated backups
- Multi-format Wiegand support

### Version 1.0 (Original)
- Basic Wiegand 26-bit support
- Simple web interface
- MySQL database

---

## License

This project is open source and available for free use, modification, and distribution.

---

## Support

- **Documentation**: [Installation Guide](pidoors/INSTALLATION_GUIDE.md)
- **Bug Reports**: [GitHub Issues](https://github.com/sybethiesant/pidoors/issues)
- **Feature Requests**: [GitHub Issues](https://github.com/sybethiesant/pidoors/issues)

---

**Built for the open source community**

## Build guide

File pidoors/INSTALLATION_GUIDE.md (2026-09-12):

# PiDoors Installation Guide

Complete step-by-step instructions for setting up the PiDoors Access Control System. This guide is designed for beginners with no prior Raspberry Pi experience.

---

## Table of Contents

1. [What You'll Need](#what-youll-need)
2. [Part 1: Setting Up Your Raspberry Pi](#part-1-setting-up-your-raspberry-pi)
3. [Part 2: Installing the Server](#part-2-installing-the-server)
4. [Part 3: Installing Door Controllers](#part-3-installing-door-controllers)
5. [Part 4: Reader Wiring Guides](#part-4-reader-wiring-guides)
   - [Wiegand Readers](#wiegand-readers)
   - [OSDP RS-485 Readers](#osdp-rs-485-readers)
   - [NFC PN532 Readers](#nfc-pn532-readers)
   - [NFC MFRC522 Readers](#nfc-mfrc522-readers)
6. [Part 5: First Login and Configuration](#part-5-first-login-and-configuration)
7. [Part 6: Adding Your First Door and Card](#part-6-adding-your-first-door-and-card)
8. [Part 7: Advanced Features](#part-7-advanced-features)
9. [Troubleshooting](#troubleshooting)
10. [Maintenance](#maintenance)
11. [Upgrading](#upgrading)

---

## What You'll Need

### For the Server (Required - One Per System)

**Hardware:**
- 1x Raspberry Pi 3B+ or newer (4GB RAM recommended)
- 1x MicroSD card (16GB minimum, 32GB recommended)
- 1x Power supply for Raspberry Pi (official recommended)
- 1x Ethernet cable (or WiFi setup)
- 1x Monitor, keyboard, mouse (for initial setup only)

**Optional:**
- Case for Raspberry Pi
- Cooling fan

### For Each Door Controller (One Per Door)

**Hardware:**
- 1x Raspberry Pi Zero W or newer per door
- 1x MicroSD card (8GB minimum)
- 1x Card reader (see options below)
- 1x 12V electric strike or magnetic lock
- 1x Relay module (to control the lock)
- 1x Door sensor (magnetic switch - optional but recommended)
- 1x Exit button / REX button (optional)
- Wiring supplies (jumper wires, terminal blocks)

**Supported Card Readers (choose one):**

| Reader Type | Interface | Formats | Cost | Notes |
|---|---|---|---|---|
| **Wiegand** | GPIO | 26/32/34/35/36/37/48-bit | $15-50 | Most common, easy setup |
| **OSDP** | RS-485 | Any | $50-150 | Encrypted, commercial-grade |
| **PN532 NFC** | I2C or SPI | Mifare, NTAG | $10-20 | Reads NFC cards/tags |
| **MFRC522 NFC** | SPI | Mifare | $5-10 | Low-cost NFC option |

**Additional Hardware for Specific Readers:**

- **OSDP**: USB to RS-485 adapter or RS-485 HAT
- **PN532 I2C**: No additional hardware (uses GPIO 2/3)
- **PN532 SPI**: No additional hardware (uses SPI0)
- **MFRC522**: No additional hardware (uses SPI0)

**Optional:**
- Custom PCB (files included in `pidoorspcb/` folder)
- Weatherproof enclosure for outdoor installations

### Software You'll Download

- Raspberry Pi Imager (free from raspberrypi.com)
- Raspberry Pi OS (downloaded via Imager)

---

## Part 1: Setting Up Your Raspberry Pi

### Step 1.1: Install Raspberry Pi OS

1. **Download Raspberry Pi Imager**
   - Go to https://www.raspberrypi.com/software/
   - Download and install Raspberry Pi Imager for your computer (Windows, Mac, or Linux)

2. **Prepare Your SD Card**
   - Insert your microSD card into your computer
   - Open Raspberry Pi Imager

3. **Choose Your Operating System**
   - Click "Choose OS"
   - Select "Raspberry Pi OS (64-bit)" (recommended) or 32-bit
   - **For Door Controllers**: You can use "Raspberry Pi OS Lite" (no desktop) to save space

4. **Choose Your SD Card**
   - Click "Choose Storage"
   - Select your SD card (be careful to select the correct one!)

5. **Configure Settings** (Important!)
   - Click the gear icon in the bottom right
   - Enable SSH: Check "Enable SSH" and select "Use password authentication"
   - Set username: `pi` and create a strong password
   - Configure WiFi if you're not using Ethernet (optional)
   - Set your timezone and keyboard layout
   - Click "Save"

6. **Write the Image**
   - Click "Write"
   - Wait for the process to complete (5-10 minutes)
   - When done, eject the SD card

### Step 1.2: First Boot

1. **Insert the SD card** into your Raspberry Pi
2. **Connect** monitor, keyboard, mouse, and Ethernet cable
3. **Power on** the Raspberry Pi by plugging in the power supply
4. **Wait** for the desktop to appear (first boot takes 1-2 minutes)
5. **Complete the welcome wizard** if it appears

### Step 1.3: Update Your Raspberry Pi

1. **Open Terminal** (black icon on the top toolbar)

2. **Update the system** by typing these commands (press Enter after each):

```bash
sudo apt-get update
sudo apt-get upgrade -y
```

This will take 10-20 minutes. Wait for it to complete.

3. **Reboot** when done:

```bash
sudo reboot
```

---

## Part 2: Installing the Server

The server hosts the web interface and database. You only need one server for your entire system.

### Step 2.1: Download PiDoors

1. **Open Terminal**

2. **Navigate to home directory**:

```bash
cd ~
```

3. **Download PiDoors** (requires internet connection):

```bash
git clone https://github.com/sybethiesant/pidoors.git
```

If you get an error that git isn't installed:

```bash
sudo apt-get install git -y
git clone https://github.com/sybethiesant/pidoors.git
```

4. **Go into the PiDoors folder**:

```bash
cd pidoors
```

### Step 2.2: Run the Automatic Installer

1. **Make the installer executable**:

```bash
chmod +x install.sh
```

2. **Run the installer as administrator**:

```bash
sudo ./install.sh
```

3. **Follow the prompts**:
   - When asked "Select installation type", choose **1** for Server
   - Wait while packages are installed (10-20 minutes)
   - When prompted for MySQL root password, create a strong password and **write it down**
   - When prompted for PiDoors database password, create another strong password and **write it down**
   - When asked to create a default admin user, choose **y** (yes)
   - Enter a username, email address, and strong password for the admin account — **write these down**
   - You can log in with either the username or email

   The installer also generates TLS certificates for encrypted database connections and configures MariaDB to use them. Door controllers will download the CA certificate automatically during their installation.

4. **Wait for completion**. You'll see a success message with the web interface URL.

### Step 2.3: Configure the Application

1. **The installer creates the config automatically**, but if you need to modify it:

```bash
sudo nano /var/www/pidoors/includes/config.php
```

2. **Key settings to verify**:
   - Database password matches what you set during installation
   - URL matches your Pi's IP address

3. **Find your Pi's IP address**:

```bash
hostname -I
```

Example output: `192.168.1.100` (your IP will be different)

4. **Save and exit** (if editing):
   - Press `Ctrl + X`
   - Press `Y` to confirm
   - Press `Enter` to save

### Step 2.4: Verify Installation

1. **Check Nginx is running**:

```bash
sudo systemctl status nginx
```

You should see "active (running)" in green.

2. **Check PHP-FPM is running**:

```bash
sudo systemctl status php*-fpm
```

You should see "active (running)" in green.

3. **Access the web interface**:
   - Open a web browser on any computer on your network
   - Navigate to: `https://192.168.1.100` (use your Pi's IP address)
   - You should see the PiDoors login page

4. **Login with**:
   - Username or Email: Either the username or email you set during installation
   - Password: The admin password you created

**If you can't access the page**, see [Troubleshooting](#troubleshooting) section.

---

## Part 3: Installing Door Controllers

Install one door controller at each door location.

### Step 3.1: Prepare the Door Pi

1. **Set up Raspberry Pi OS** on a new SD card (follow Part 1 steps)
   - You can use Raspberry Pi OS Lite (no desktop needed)

2. **Boot and connect** to the network

3. **Update the system**:

```bash
sudo apt-get update
sudo apt-get upgrade -y
sudo reboot
```

### Step 3.2: Install PiDoors on Door Controller

1. **Download PiDoors**:

```bash
cd ~
git clone https://github.com/sybethiesant/pidoors.git
cd pidoors
```

2. **Run the installer**:

```bash
chmod +x install.sh
sudo ./install.sh
```

3. **Select installation type**: Choose **2** for Door Controller

4. **Follow the prompts**:
   - Database server IP: Enter your server Pi's IP (e.g., `192.168.1.100`)
   - Database password: Enter the PiDoors database password
   - Door name: Give this door a short name, lowercase with underscores (e.g., `front_door`, `back_gate`)
   - **Reader type**: Select your card reader type:
     - **1) Wiegand** - Standard GPIO card readers (most common)
     - **2) OSDP** - RS-485 encrypted readers
     - **3) NFC PN532** - PN532 NFC reader via I2C
     - **4) NFC MFRC522** - MFRC522 NFC reader via SPI

   The installer automatically downloads the TLS certificate from the server to encrypt database connections. If the server hasn't been updated to v2.6.0+ yet, the controller will still work with unencrypted connections.

### Step 3.3: Enable Required Interfaces

Depending on your reader type, you may need to enable additional interfaces:

**For SPI readers (PN532 SPI, MFRC522):**
```bash
sudo raspi-config
# Navigate to: Interface Options > SPI > Enable
sudo reboot
```

**For I2C readers (PN532 I2C):**
```bash
sudo raspi-config
# Navigate to: Interface Options > I2C > Enable
sudo reboot
```

**For OSDP readers (Serial/UART):**
```bash
sudo raspi-config
# Navigate to: Interface Options > Serial Port
# Login shell over serial: No
# Serial port hardware enabled: Yes
sudo reboot
```

### Step 3.4: Wire Your Reader

See [Part 4: Reader Wiring Guides](#part-4-reader-wiring-guides) for detailed wiring instructions for your specific reader type.

---

## Part 4: Reader Wiring Guides

**IMPORTANT: Power off the Raspberry Pi before wiring!**

```bash
sudo shutdown -h now
```

### Wiegand Readers

Wiegand is the most common card reader interface. Supports 26, 32, 34, 35, 36, 37, and 48-bit formats with automatic detection.

**Wiegand Reader Wiring:**

> **Voltage Warning:** Wiegand readers output 5V logic, but the Pi's GPIO pins are 3.3V. Use a **bi-directional logic level shifter** on the DATA0 and DATA1 lines to protect the Pi. Connecting 5V signals directly to GPIO pins can damage them.

| Wiegand Reader | Level Shifter | Raspberry Pi | Pin # |
|---|---|---|---|
| DATA0 (Green)  | HV1 → LV1 | GPIO 24 | 18 |
| DATA1 (White)  | HV2 → LV2 | GPIO 23 | 16 |
| GND (Black) | GND (shared)  | GND | 6 |
| 5V+ (Red) | HV ref | 5V | 2 |
| — | LV ref | 3V3 | 1 |

**Lock Control (Relay) - All Reader Types:**

| Relay Module | Raspberry Pi | Pin # |
|---|---|---|
| IN (Signal) | GPIO 18 | 12 |
| VCC | 5V | 4 |
| GND | GND | 14 |

Connect your electric lock to the relay's NO (Normally Open) and COM terminals with a 12V power supply.

**Configuration file:** `/opt/pidoors/conf/config.json`
```json
{
    "front_door": {
        "reader_type": "wiegand",
        "d0": 24,
        "d1": 23,
        "wiegand_format": "auto",
        "latch_gpio": 18,
        ...
    }
}
```

---

### OSDP RS-485 Readers

OSDP (Open Supervised Device Protocol) provides encrypted communication with commercial-grade readers. Requires a USB-to-RS-485 adapter or RS-485 HAT.

**USB-RS485 Adapter Wiring:**

| RS-485 Adapter | OSDP Reader |
|---|---|
| A+ (Data+) | A+ (Data+)  |
| B- (Data-) | B- (Data-)  |
| GND | GND |

**Note:** The reader needs its own 12V power supply. Do not power from the Pi.

**Relay wiring is the same as Wiegand above.**

**Configuration file:** `/opt/pidoors/conf/config.json`
```json
{
    "secure_door": {
        "reader_type": "osdp",
        "serial_port": "/dev/ttyUSB0",
        "baud_rate": 115200,
        "address": 0,
        "latch_gpio": 18,
        ...
    }
}
```

**For encrypted OSDP (Secure Channel)**, add the encryption key:
```json
"encryption_key": "base64_encoded_16_byte_key"
```

---

### NFC PN532 Readers

The PN532 is a versatile NFC reader supporting Mifare Classic, Ultralight, and NTAG cards. Can use I2C or SPI interface.

**PN532 I2C Wiring (Recommended):**

| PN532 Module | Raspberry Pi | Pin # |
|---|---|---|
| VCC | 3.3V | 1 |
| GND | GND | 6 |
| SDA | GPIO 2 (SDA) | 3 |
| SCL | GPIO 3 (SCL) | 5 |

**Important:** Set the PN532 DIP switches to I2C mode (usually both switches OFF or check your module's documentation).

**Relay wiring is the same as Wiegand above.**

**Configuration file:** `/opt/pidoors/conf/config.json`
```json
{
    "nfc_door": {
        "reader_type": "nfc_pn532",
        "interface": "i2c",
        "i2c_bus": 1,
        "i2c_address": 36,
        "latch_gpio": 18,
        ...
    }
}
```

**PN532 SPI Wiring (Alternative):**

| PN532 Module | Raspberry Pi | Pin # |
|---|---|---|
| VCC | 3.3V | 1 |
| GND | GND | 6 |
| SCK | GPIO 11 (SCLK) | 23  |
| MISO | GPIO 9 (MISO)  | 21  |
| MOSI | GPIO 10 (MOSI) | 19  |
| SS | GPIO 8 (CE0) | 24  |

---

### NFC MFRC522 Readers

The MFRC522 is an inexpensive NFC reader for Mifare cards. Uses SPI interface only.

**MFRC522 SPI Wiring:**

| MFRC522 Module | Raspberry Pi | Pin # |
|---|---|---|
| VCC (3.3V) | 3.3V | 1 |
| GND | GND | 6 |
| RST | GPIO 25 | 22 |
| SCK | GPIO 11 (SCLK) | 23  |
| MISO | GPIO 9 (MISO)  | 21  |
| MOSI | GPIO 10 (MOSI) | 19  |
| SDA (SS) | GPIO 8 (CE0) | 24  |
| IRQ | Not connected | - |

**Relay wiring is the same as Wiegand above.**

**Configuration file:** `/opt/pidoors/conf/config.json`
```json
{
    "rfid_door": {
        "reader_type": "nfc_mfrc522",
        "spi_bus": 0,
        "spi_device": 0,
        "reset_pin": 25,
        "latch_gpio": 18,
        ...
    }
}
```

---

### GPIO Pin Reference (All Readers)

```
    3V3  (1) (2)  5V      <- Power for readers
  GPIO2  (3) (4)  5V      <- I2C SDA
  GPIO3  (5) (6)  GND     <- I2C SCL
  GPIO4  (7) (8)  GPIO14  <- UART TX (OSDP)
    GND  (9) (10) GPIO15  <- UART RX (OSDP)
 GPIO17 (11) (12) GPIO18  <- Lock relay
 GPIO27 (13) (14) GND     <- Door sensor (optional)
 GPIO22 (15) (16) GPIO23  <- Wiegand D1
    3V3 (17) (18) GPIO24  <- Wiegand D0
 GPIO10 (19) (20) GND     <- SPI MOSI
  GPIO9 (21) (22) GPIO25  <- MFRC522 Reset
 GPIO11 (23) (24) GPIO8   <- SPI SCLK / SPI CE0
    GND (25) (26) GPIO7
```

---

### Step 3.5: Start the Door Controller

1. **Power on the Raspberry Pi**

2. **Check if the service is running**:

```bash
sudo systemctl status pidoors
```

You should see "active (running)" in green.

3. **View real-time logs**:

```bash
sudo journalctl -u pidoors -f
```

Press `Ctrl + C` to stop viewing logs.

4. **Test by scanning a card** - you should see the card number appear in the logs

---

## Part 5: First Login and Configuration

### Step 5.1: Change Default Password

1. **Log into the web interface** (https://your-server-ip) using your username or email
2. **Click your name** in the top right corner
3. **Click "Profile"**
4. **Update your profile details** (name, phone, department, etc.) and **change your password**
5. **Click "Update Profile"**

### Step 5.2: Configure System Settings

1. **Go to Settings** (in the sidebar, under Admin Tools)

2. **Configure basic settings**:
   - System Name: Give your system a name
   - Timezone: Set your timezone
   - Session Timeout: 3600 seconds (1 hour) is recommended

3. **Configure Email Notifications** (optional):
   - Enable Email Notifications: Check the box
   - Notification Email: Enter the email address to receive security alerts

4. **Click "Save Settings"**

### Step 5.3: Configure Your Doors

Doors can be added two ways:

**Automatic:** When a door controller starts and sends its first heartbeat, it auto-registers in the database. You'll see it appear on the Doors page.

**Manual (via web UI):**

1. **Go to "Doors"** in the sidebar
2. **Click "Add Door"**
3. **Fill in the form**:
   - Name: A lowercase name with underscores (e.g., "front_door", "back_gate") — the form normalizes this automatically
   - Location: Description or building location
   - Unlock Duration: How long to unlock (5 seconds is typical)
   - Reader Type: Select your card reader type
   - Schedule: Leave blank for 24/7 access (you can create schedules later)

4. **Click "Add Door"**

5. **Verify the door status**:
   - Go back to "Doors"
   - You should see your door listed
   - Status should turn green ("Online") once the controller connects

---

## Part 6: Adding Your First Door and Card

### Step 6.1: Scan a Card to Get Its ID

1. **At the door controller**, scan a card on the reader

2. **View the logs** to get the card number:

```bash
sudo journalctl -u pidoors -n 20
```

3. **Look for a line like**:
```
Card read: 12345678
Access denied: Card not in database
```

4. **Write down the card number** (e.g., 12345678)

### Step 6.2: Add the Card to the System

1. **In the web interface**, go to **"Cards"**
2. **Click "Add Card"**
3. **Fill in the form**:
   - Card ID: The number you wrote down (e.g., 12345678)
   - User ID: A unique identifier (e.g., EMP001, JOHN001)
   - Facility Code: The facility code from the reader
   - First Name / Last Name: Card holder's name
   - Door Access: Select which doors this card can open
   - Access Group: Leave blank for now (full access)
   - Schedule: Leave blank for 24/7 access
   - Valid From / Valid Until: Leave blank for no date restrictions
   - Active: Check this box
   - **Cardholder Details (optional):** Email, phone, department, employee ID, company, title, notes — for corporate record-keeping

4. **Click "Add Card"**

### Step 6.3: Test the Card

1. **Go to the door** and scan the card again
2. **The door should unlock!**
3. **Verify in the web interface**:
   - Go to "Access Logs"
   - You should see a new entry with "Granted" status in green

---

## Part 7: Advanced Features

### Creating Access Schedules

1. **Go to "Schedules"**
2. **Click "Add Schedule"**
3. **Give it a name** (e.g., "Business Hours")
4. **Set time windows** for each day:
   - Monday-Friday: 8:00 AM - 5:00 PM
   - Saturday-Sunday: Closed (leave blank)

5. **Assign to cards**:
   - Edit a card
   - Select the schedule
   - Save

Now that card only works during business hours!

### Creating Access Groups

1. **Go to "Access Groups"**
2. **Click "Add Group"**
3. **Give it a name** (e.g., "Employees", "Management")
4. **Select which doors** this group can access
5. **Assign cards to the group**:
   - Edit a card
   - Select the group
   - Save

### Setting Up Holidays

1. **Go to "Holidays"**
2. **Click "Add Holiday"**
3. **Enter**:
   - Name: Holiday name
   - Date: The date
   - Access Type: "Deny All" or "Allow All"
4. **Save**

Cards will respect holiday settings automatically!

### Gate Mode (Rolling/Sliding Gates)

PiDoors supports **gate motor controllers** in addition to electronic door locks. Gate mode replaces the lock relay with a set of input/output relays that interface with commercial gate motor controllers.

**To enable gate mode:**

1. **Go to "Doors"** in the web UI
2. **Click the edit (pencil) icon** on the door you want to convert
3. **Check the "Gate mode" box**
4. **Configure the I/O** under "Gate I/O Configuration":

   **Inputs (physical buttons or RF remote relays):**
   - **Open button** — Triggers the open output. Triple-tap = enter hold-open state.
   - **Stop button** — Cuts the active output immediately. Triple-tap = hold at current position.
   - **Close button** — Triggers the close output. Triple-tap = enter hold-closed state.

   **Outputs (relays to gate motor):**
   - **Open relay** — Held active for the configured duration to open the gate
   - **Stop relay** — Optional, fires when stop is triggered (only needed if your motor has a dedicated stop input)
   - **Close relay** — Held active for the configured duration to close the gate

5. **Each input/output is optional** — only enable what your hardware supports. Pin numbers, polarity (active high/low), and (for outputs) hold duration are configurable per input/output.

6. **Save**. The controller will reload its config and switch to gate mode.

**Hold duration:** Each output relay has its own configurable hold time (default 30 seconds). This is how long the relay stays active to drive the gate motor.

**Polarity:** "Active high" = relay engages when GPIO is at 3.3V. "Active low" = relay engages when GPIO is at GND. Most relay modules with optocouplers are active low.

**Pin conflicts:** The web UI shows only available GPIO pins (excluding ones used by your reader, sensor, status LED, and other gate I/O). The system prevents double-assignment.

**Card scans on a gate:** A successful card scan triggers the open output (just like a card scan unlocks a door). Master card 3-scan enters the hold-open state. A single master scan releases any hold state.

**Web UI control:** When a door is in gate mode, the door card on the Doors page shows dedicated **Open / Stop / Close / Hold / Release** buttons and a live state badge (idle / opening / closing / stopped / open / closed / held).

**Wiring:** Wire each output relay's NO/COM terminals to the corresponding input on your gate motor controller. Wire each input button between the assigned GPIO pin and GND (default pull-up mode). For dry-contact switches no level shifter is needed; for 5V signals (like RF remote relay outputs) use a bi-directional logic level shifter.

**Status persistence:** The current gate state and hold flag are saved to the database and restored on controller restart, so a power cycle won't accidentally release a held gate.

### Reader LED (Optional)

The reader LED follows the door: green / on while it is unlocked or held open (by a card, a schedule, a master card or an admin), red / off when locked, and a red blink on a denied card. Edit any door and use the **Reader LED** section:

- **LED pin (green / open)** — the only pin needed for readers with a single LED control line (most HID / Wiegand readers; set **Active** to *Low* if pulling the line low turns the LED green).
- **Red pin (optional)** — for keypads with separate red and green inputs or a two-wire bicolor LED.

The default, shown preselected on a door that never configured an LED, is the original wiring: GPIO 25 green, GPIO 22 red. Works on doors and gates and is applied on the next config push, no restart needed.

### Importing Multiple Cards from CSV

1. **Create a CSV file** with this format:

```csv
card_id,user_id,firstname,lastname,email,department
12345678,EMP001,John,Smith,john@example.com,Engineering
23456789,EMP002,Jane,Doe,jane@example.com,Marketing
34567890,EMP003,Bob,Wilson,bob@example.com,Operations
```

Only `card_id` and `user_id` are required. Optional columns: `firstname`, `lastname`, `email`, `phone`, `department`, `employee_id`, `company`, `title`, `notes`, `group_id`, `schedule_id`, `valid_from`, `valid_until`, `pin_code`.

2. **Go to "Import CSV"** (from the Cards page)
3. **Upload your CSV file**
4. **Click "Import Cards"**

All cards will be added at once!

---

## Troubleshooting

### Problem: Can't access the web interface

**Solution 1: Check if Nginx is running**
```bash
sudo systemctl status nginx
```

If it's not running:
```bash
sudo systemctl start nginx
```

**Solution 2: Check if PHP-FPM is running**
```bash
sudo systemctl status php*-fpm
```

If it's not running:
```bash
sudo systemctl start php*-fpm
```

**Solution 3: Verify the IP address**
```bash
hostname -I
```

Use the first IP address shown.

**Solution 4: Check firewall**
```bash
sudo ufw allow 80/tcp
sudo ufw allow 443/tcp
```

**Solution 5: Check Nginx error log**
```bash
sudo tail -50 /var/log/nginx/pidoors_error.log
```

### Problem: Door controller shows "offline" in web interface

**Solution 1: Check if service is running**
```bash
sudo systemctl status pidoors
```

If not running:
```bash
sudo systemctl start pidoors
```

**Solution 2: Check database connection**
```bash
sudo journalctl -u pidoors -n 50
```

Look for connection errors.

**Solution 3: Verify network connectivity**
```bash
ping -c 4 192.168.1.100
```
(Replace with your server IP)

**Solution 4: Check configuration file**
```bash
cat /opt/pidoors/conf/config.json
```

Verify the server IP and database password are correct.

### Problem: Card not working

**Solution 1: Check if card is in the database**
- Go to "Cards" in web interface
- Search for the card ID

**Solution 2: Check if card is active**
- Edit the card
- Make sure "Active" is checked

**Solution 3: Check access logs**
- Go to "Access Logs"
- Look for the card attempt
- Check the denial reason

**Solution 4: Verify Wiegand wiring**
```bash
sudo journalctl -u pidoors -f
```
Scan a card - you should see the card number appear.

### Problem: NFC reader (PN532/MFRC522) not detecting cards

**Solution 1: Verify SPI/I2C is enabled**
```bash
# For SPI readers:
ls /dev/spidev*
# Should show /dev/spidev0.0

# For I2C readers:
ls /dev/i2c*
# Should show /dev/i2c-1
```

If not present, enable via raspi-config:
```bash
sudo raspi-config
# Interface Options > SPI or I2C > Enable
sudo reboot
```

**Solution 2: Check I2C device detection (PN532 I2C)**
```bash
sudo apt install -y i2c-tools
sudo i2cdetect -y 1
```
You should see address `24` (0x24) in the grid.

**Solution 3: Check wiring connections**
- Verify 3.3V (not 5V!) for NFC modules
- Check all SPI/I2C connections are secure
- For MFRC522, verify RST pin is connected to GPIO 25

**Solution 4: Check PN532 DIP switches**
- For I2C mode: Usually both switches OFF
- For SPI mode: Usually SW1=ON, SW2=OFF
- Consult your module's documentation

**Solution 5: Test SPI communication**
```bash
# Check if SPI driver is loaded
lsmod | grep spi
```

### Problem: OSDP reader not responding

**Solution 1: Verify serial port**
```bash
# For USB adapter:
ls /dev/ttyUSB*
# Should show /dev/ttyUSB0

# For GPIO UART:
ls /dev/serial0
```

**Solution 2: Check RS-485 wiring**
- Verify A+ to A+ and B- to B- connections
- Check for proper termination (120 ohm resistor may be needed)
- Ensure GND is connected

**Solution 3: Verify UART is enabled (for GPIO serial)**
```bash
sudo raspi-config
# Interface Options > Serial Port
# Login shell: No
# Serial hardware: Yes
```

**Solution 4: Check baud rate**
- Most OSDP readers use 9600 or 115200 baud
- Verify setting matches your reader

**Solution 5: Test serial communication**
```bash
# Install screen
sudo apt install screen

# Connect (press Ctrl+A then K to exit)
sudo screen /dev/ttyUSB0 9600
```

**Solution 6: Check OSDP address**
- Default address is usually 0
- Some readers use address 1 or allow configuration

### Problem: Door won't unlock even with valid card

**Solution 1: Check relay wiring**
- Verify GPIO 18 connection to relay (default pin)
- Test relay manually:
```bash
# Test using Python (uses lgpio on Bookworm+)
/opt/pidoors/venv/bin/python3 -c "
import RPi.GPIO as GPIO
GPIO.setmode(GPIO.BCM)
GPIO.setup(18, GPIO.OUT)
GPIO.output(18, GPIO.HIGH)
import time; time.sleep(2)
GPIO.output(18, GPIO.LOW)
GPIO.cleanup()
"
```

**Solution 2: Check lock power**
- Ensure 12V power supply is connected
- Check lock current draw (should be < 1A)

**Solution 3: Check unlock duration**
- Go to "Doors" > Edit your door
- Increase "Unlock Duration" to 10 seconds
- Test again

### Problem: Forgot admin password

**Solution: Reset password via database**
```bash
# Generate new password hash in PHP
php -r "echo password_hash('newpassword', PASSWORD_BCRYPT);"

# Copy the output, then update database:
mysql -u pidoors -p
```

In MySQL:
```sql
USE users;
UPDATE users SET user_pass = 'paste_hash_here' WHERE user_email = 'your@email.com' OR user_name = 'yourusername';
EXIT;
```

### Problem: Database connection errors

**Solution: Verify database credentials**

1. Test connection:
```bash
mysql -u pidoors -p
```

2. If it fails, reset the password:
```bash
sudo mysql -u root -p
```

In MySQL:
```sql
ALTER USER 'pidoors'@'localhost' IDENTIFIED BY 'new_password';
FLUSH PRIVILEGES;
EXIT;
```

3. Update config.php with new password:
```bash
sudo nano /var/www/pidoors/includes/config.php
```

### Getting More Help

1. **Check the logs**:
   - Door controller: `sudo journalctl -u pidoors -f`
   - Nginx errors: `sudo tail -f /var/log/nginx/pidoors_error.log`
   - PHP errors: `sudo tail -f /var/log/nginx/pidoors_error.log`
   - MySQL errors: `sudo tail -f /var/log/mysql/error.log`

2. **Check the audit log** in the web interface (Admin Tools > Audit Log)

3. **Restart services**:
   ```bash
   sudo systemctl restart nginx
   sudo systemctl restart php*-fpm
   sudo systemctl restart pidoors
   sudo systemctl restart mysql
   ```

4. **Test Nginx configuration**:
   ```bash
   sudo nginx -t
   ```

---

## Maintenance

### Daily Backups (Automatic)

Backups run automatically (if configured) to `/var/backups/pidoors/`

### Manual Backup

```bash
sudo /usr/local/bin/pidoors-backup.sh YOUR_DB_PASSWORD
```

### Restore from Backup

```bash
mysql -u pidoors -p users < /var/backups/pidoors/users_YYYYMMDD_HHMMSS.sql
mysql -u pidoors -p access < /var/backups/pidoors/access_YYYYMMDD_HHMMSS.sql
```

### Update PiDoors

**Recommended: One-click update from the web UI**

1. Go to **Settings** in the web interface
2. Click **Check for Updates**
3. If an update is available, click **Update Now**

The web updater handles file deployment, stale file cleanup, and version tracking automatically.

**Alternative: Manual update from the command line**

```bash
cd ~/pidoors
git pull
sudo cp -r pidoorserv/* /var/www/pidoors/
sudo cp VERSION /var/www/pidoors/
sudo chown -R www-data:www-data /var/www/pidoors
sudo systemctl restart nginx
sudo systemctl restart php*-fpm
```

**Door controllers** update automatically via the heartbeat system. You can also trigger updates from the **Doors** page in the web UI. For manual updates:

```bash
cd ~/pidoors
git pull
sudo cp pidoors/pidoors.py /opt/pidoors/
sudo cp VERSION /opt/pidoors/
sudo cp -r pidoors/readers/* /opt/pidoors/readers/
sudo cp -r pidoors/formats/* /opt/pidoors/formats/
sudo systemctl restart pidoors
```

### Database Migrations

When upgrading PiDoors, always run the migration script to ensure your database has all required columns:

```bash
# Backup first
mysqldump -u pidoors -p access > access_backup_$(date +%Y%m%d).sql
mysqldump -u pidoors -p users > users_backup_$(date +%Y%m%d).sql

# Run migration (safe to re-run, uses IF NOT EXISTS checks)
mysql -u root -p access < database_migration.sql
```

The migration script handles both the `access` and `users` databases. It adds any missing columns (extended user profiles, cardholder fields, indexes) without affecting existing data.

#### v2.2.1 Migration (Required if upgrading from v2.2 or earlier)

**What changed:** Door assignments are now stored as comma-separated values instead of space-separated for improved security. This migration converts existing records.

**Why it's required:** The security fix uses `FIND_IN_SET()` SQL function which requires comma-separated values. Without this migration, existing cards may lose door access.

**Step 1: Backup your database first!**
```bash
mysqldump -u pidoors -p access > access_backup_$(date +%Y%m%d).sql
```

**Step 2: Run the migration (choose one method)**

**Option A: Python script (Recommended - safer with preview)**
```bash
cd ~/pidoors

# Preview changes first (no modifications made)
python3 migrations/migrate_doors_format.py --dry-run

# If the preview looks correct, apply changes
python3 migrations/migrate_doors_format.py
```

The Python script will:
- Show you exactly what will change before making changes
- Ask for confirmation before applying
- Can be safely run multiple times

**Option B: SQL script (Direct database update)**
```bash
cd ~/pidoors
mysql -u pidoors -p access < migrations/migrate_doors_format.sql
```

**Step 3: Verify the migration**
```bash
# Check no space-separated values remain
mysql -u pidoors -p access -e "SELECT COUNT(*) FROM cards WHERE doors LIKE '% %' AND doors != '*';"
# Should return 0
```

**Step 4: Restart door controllers**
```bash
sudo systemctl restart pidoors
```

**Example of what changes:**

| Before (space-separated) | After (comma-separated) |
|---|---|
| `front_door back_door` | `front_door,back_door`  |
| `lobby entrance exit` | `lobby,entrance,exit` |
| `*` (all doors) | `*` (unchanged) |
| `single_door` | `single_door` (unchanged) |

### HTTPS (Automatic)

HTTPS is configured automatically during installation. The installer generates a CA-signed TLS certificate (valid for 10 years) using the PiDoors CA that is also used for MariaDB TLS. The nginx config includes:

- TLS 1.2+ enforced with strong cipher suite
- HSTS header (`max-age=63072000`)
- Content-Security-Policy headers
- API rate limiting
- HTTP automatically redirects to HTTPS

No manual configuration is needed. If you need to regenerate the certificate (e.g., after an IP change), run:

```bash
sudo openssl genrsa 2048 > /etc/ssl/private/pidoors.key
SERVER_IP=$(hostname -I | awk '{print $1}')
sudo openssl req -new -key /etc/ssl/private/pidoors.key -out /tmp/pidoors.csr -subj "/CN=PiDoors Web"
echo "subjectAltName = IP:${SERVER_IP},DNS:pidoors,DNS:pidoors.local,DNS:localhost,IP:127.0.0.1" > /tmp/pidoors-ext.cnf
sudo openssl x509 -req -days 3650 -in /tmp/pidoors.csr -CA /etc/mysql/ssl/ca.pem -CAkey /etc/mysql/ssl/ca-key.pem -CAcreateserial -out /etc/ssl/certs/pidoors.crt -extfile /tmp/pidoors-ext.cnf
rm -f /tmp/pidoors.csr /tmp/pidoors-ext.cnf
sudo nginx -t && sudo systemctl reload nginx
```

---

## Next Steps

Now that your system is running:

1. Add all your doors
2. Import or add all your cards
3. Create access schedules if needed
4. Create access groups for different user types
5. Set up email notifications
6. Test the backup system
7. Monitor the system via the dashboard

**Your PiDoors Access Control System is now operational!**

---

## Upgrading

### General Upgrade Procedure

For most upgrades, use the **one-click web UI updater** (Settings > Check for Updates). For manual upgrades:

```bash
cd ~/pidoors
git pull

# Server
sudo cp -r pidoorserv/* /var/www/pidoors/
sudo cp VERSION /var/www/pidoors/
sudo chown -R www-data:www-data /var/www/pidoors
sudo systemctl restart nginx && sudo systemctl restart php*-fpm

# Run database migration if upgrading across major versions
mysqldump -u pidoors -p access > access_backup_$(date +%Y%m%d).sql
mysqldump -u pidoors -p users > users_backup_$(date +%Y%m%d).sql
mysql -u root -p access < database_migration.sql
```

Door controllers can be updated from the **Doors** page in the web UI, or manually:

```bash
cd ~/pidoors && git pull
sudo cp pidoors/pidoors.py /opt/pidoors/
sudo cp VERSION /opt/pidoors/
sudo cp -r pidoors/readers/* /opt/pidoors/readers/
sudo cp -r pidoors/formats/* /opt/pidoors/formats/
sudo systemctl restart pidoors
```

### Upgrading from v2.2.x or earlier

If upgrading from v2.2.x or earlier, you must run the door format migration:

```bash
mysqldump -u pidoors -p access > access_backup_$(date +%Y%m%d).sql
python3 migrations/migrate_doors_format.py --dry-run
python3 migrations/migrate_doors_format.py
```

This converts door assignments from space-separated to comma-separated format (required for `FIND_IN_SET()` security fix).

On Debian 12+ (Bookworm/Trixie), ensure the GPIO library is correct:
```bash
sudo /opt/pidoors/venv/bin/pip uninstall RPi.GPIO -y 2>/dev/null
sudo /opt/pidoors/venv/bin/pip install rpi-lgpio -q
```

### Version History

| Version | Date | Migration Required | Notes |
|---|---|---|---|
| v3.1.5 | Mar 2026 | No | Fix updater deleting ca.pem, auto-restore CA cert on update |
| v3.1.4 | Mar 2026 | No | Fix false offline status when push fails, better install diagnostics |
| v3.1.3 | Mar 2026 | No | Fix CA key permissions for cert signing, UI improvements |
| v3.1.2 | Mar 2026 | No | Docker rewrite (2 containers), install.sh HTTPS fix, CSP fix |
| v3.1.1 | Mar 2026 | No | Security hardening, CA-signed TLS, admin re-verification |
| v3.1.0 | Mar 2026 | No | Server-initiated status polling, parallel curl_multi |
| v3.0.x | Mar 2026 | No | React SPA, REST API, push-based communication |
| v2.6.1 | Mar 2026 | No | Fix fresh install login, fix controller SSL errors |
| v2.6.0 | Mar 2026 | No | TLS database encryption, centralized DB helper |
| v2.5.20 | Mar 2026 | No | Remote door unlock from web UI, command poll loop |
| v2.5.19 | Mar 2026 | No | Fix controller self-update script |
| v2.5.18 | Mar 2026 | No | Upgrade Bootstrap to 5.3.8 |
| v2.5.17 | Mar 2026 | No | Audit log detail modals, rich change logging, card audit trails |
| v2.5.16 | Mar 2026 | No | Fix white-page on redirects, fix CSV exports |
| v2.5.15 | Mar 2026 | No | Stale file cleanup in all updaters |
| v2.5.14 | Mar 2026 | No | System audit fixes, secure password handling |
| v2.5.13 | Mar 2026 | No | Database audit fixes |
| v2.5.x | Feb-Mar 2026 | No | Update system, backup system, bug fixes |
| v2.4.x | Feb 2026 | **Yes** - `database_migration.sql` | Master card UI, extended fields, GPIO/lgpio fix |
| v2.3.0 | Feb 2026 | **Yes** - `database_migration.sql` | Extended user/cardholder fields, username login |
| v2.2.1 | Jan 2026 | **Yes** - `migrate_doors_format.py` | Security fix for zone matching |
| v2.2 | Jan 2026 | No | Multi-reader support |
| v2.0 | Jan 2026 | Yes - `database_migration.sql` | Security overhaul |

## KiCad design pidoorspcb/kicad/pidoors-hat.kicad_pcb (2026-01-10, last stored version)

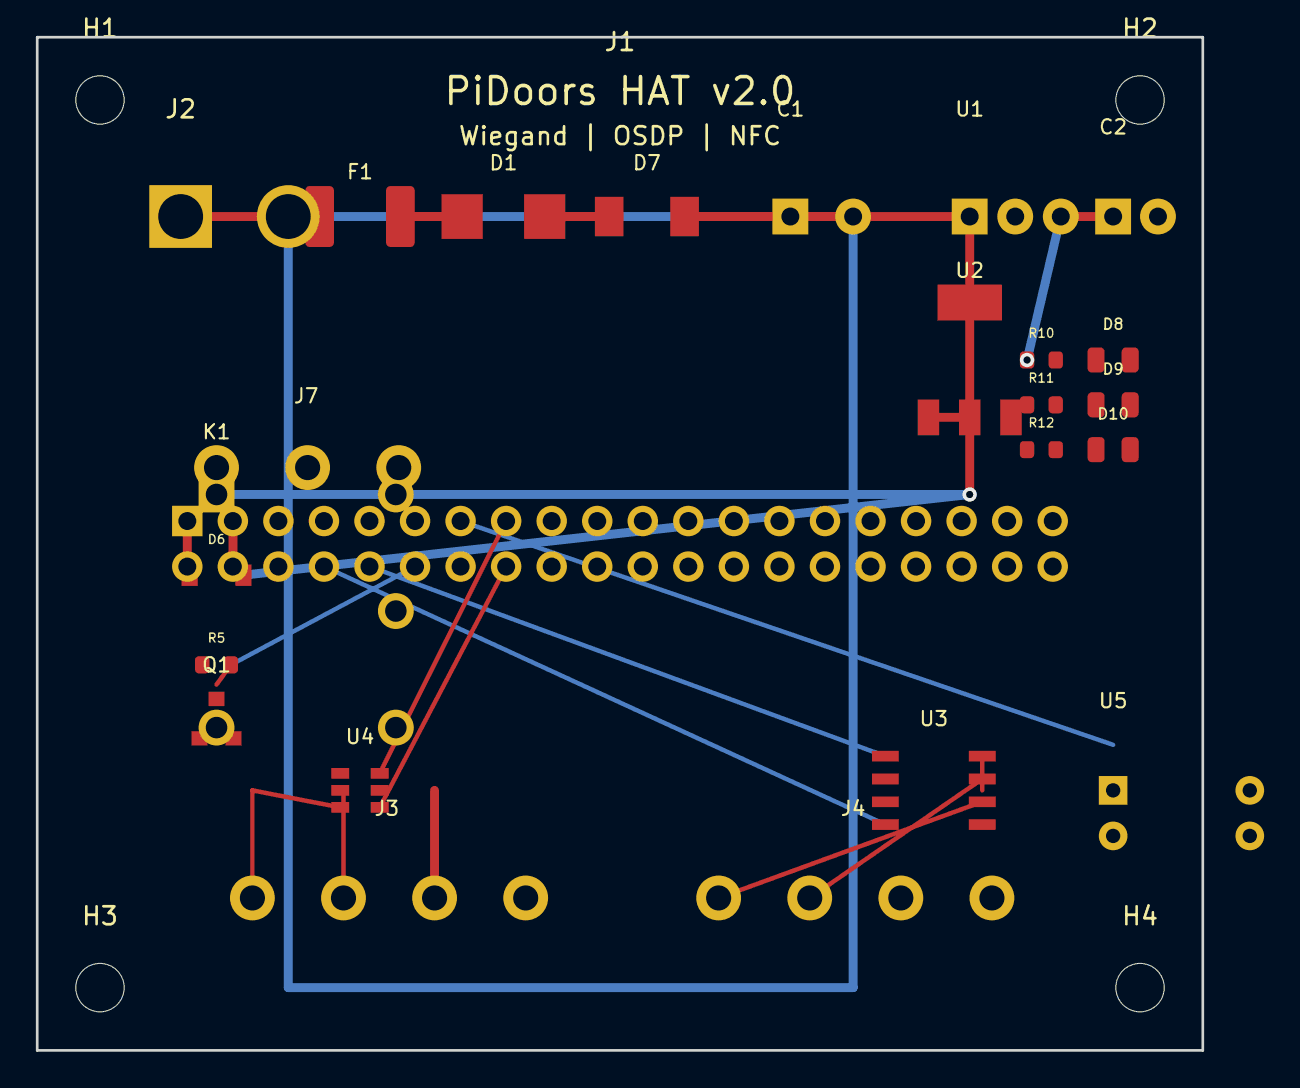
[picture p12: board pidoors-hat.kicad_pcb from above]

Board: 2 copper layers, 65.0 x 56.5 mm, 29 parts (0 on the bottom side), 23 nets.

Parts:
C1: 100uF/35V; CP_Radial_D8.0mm_P3.50mm
C2: 100uF/10V; CP_Radial_D6.3mm_P2.50mm
D1: SMBJ24A; D_SMB
D6: 1N4148W; D_SOD-123
D7: SS34; D_SMA
D8: PWR; LED_0805_2012Metric
D9: OK; LED_0805_2012Metric
D10: ERR; LED_0805_2012Metric
F1: 1.1A; Fuse_1812_4532Metric
H1, H2, H3, H4: MountingHole; MountingHole_2.7mm_M2.5
J1: Raspberry_Pi; PinSocket_2x20_P2.54mm_Vertical
J2: 12V DC; BarrelJack_CUI_PJ-002A_Horizontal
J3: Wiegand; TerminalBlock_Phoenix_MKDS-1,5-4-5.08_1x04_P5.08mm_Horizont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
J4: RS485; TerminalBlock_Phoenix_MKDS-1,5-4-5.08_1x04_P5.08mm_Horizont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
J7: Relay_Out; TerminalBlock_Phoenix_MKDS-1,5-3-5.08_1x03_P5.08mm_Horizont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
K1: G5LE-14_DC12; Relay_SPDT_Omron-G5LE-14
Q1: MMBT2222A; SOT-23
R5, R10: 1k; R_0603_1608Metric
R11: 330; R_0603_1608Metric
R12: 220; R_0603_1608Metric
U1: OKI-78SR-5; Converter_DCDC_muRata_OKI-78SRx_Vertical
U2: LD1117S33; SOT-223-3_TabPin2
U3: MAX13487E; SOIC-8_3.9x4.9mm_P1.27mm
U4: TXB0102; SOT-23-6
U5: PC817; DIP-4_W7.62mm

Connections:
+3V3: J1.1, J1.17, U2.2, U2.4, U3.8, U4.1, U5.4
+5V: C2.1, D7.2, J1.2, J1.4, J3.3, R10.1, U1.3, U2.3, U4.2
+12V: F1.1, J2.1
+12V_FUSED: C1.1, D1.2, D6.2, D7.1, F1.2, K1.1, U1.1
GND: C1.2, C2.2, D1.1, D8.2, J1.6, J1.9, J1.14, J1.20, J1.25, J1.30, J1.34, J1.39, J2.2, J3.4, J4.3, Q1.3, U1.2, U2.1, U3.5
GPIO14_TX: J1.8, U3.4
GPIO15_RX: J1.10, U3.1
GPIO18_RELAY: J1.12, R5.1
GPIO22_LED_ERR: J1.15, R12.1
GPIO23_D1: J1.16, U4.6
GPIO24_D0: J1.18, U4.4
GPIO25_LED_OK: J1.22, R11.1
GPIO27_DOOR: J1.13, U5.3
LED_ERR_ANODE: D10.1, R12.2
LED_OK_ANODE: D9.1, R11.2
PWR_LED: D8.1, R10.2
RELAY_BASE: Q1.1, R5.2
RELAY_COIL: D6.1, K1.2, Q1.2
RELAY_COM: J7.2, K1.4
RELAY_NC: J7.3, K1.5
RELAY_NO: J7.1, K1.3
RS485_A: J4.1, U3.6
RS485_B: J4.2, U3.7

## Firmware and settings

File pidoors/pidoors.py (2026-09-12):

#!/usr/bin/python3
"""
PiDoors Access Control - Door Controller
Wiegand-based access control system for Raspberry Pi

Features:
- Wiegand 26, 32, 34, 35, 36, 37, 48-bit card reading
- OSDP reader module (present, not yet wired into the controller)
- NFC/RFID reader modules PN532 / MFRC522 (present, not yet wired into the controller)
- Local 24-hour cache for offline operation
- Persistent master cards for emergency access (bounded fail-open during outages)
- Time-based access schedules
- Scheduled unlock (hold a door/gate open during a schedule's hours)
- Lockdown mode (deny all non-master cards when a door is locked down)
- Door sensor monitoring
- REX (Request to Exit) button support
- Health check/heartbeat to server
- Automatic database reconnection
"""

from datetime import datetime, timedelta
import sys
import os

# Ensure install dir is in sys.path for local imports (formats, readers)
# even when WorkingDirectory is set to a runtime dir for lgpio temp files
_install_dir = os.environ.get('PIDOORS_DIR', '/opt/pidoors')
if _install_dir not in sys.path:
    sys.path.insert(0, _install_dir)

import RPi.GPIO as GPIO
import time
import signal
import json
import threading
import syslog
import socket
import fcntl
import subprocess
import hmac
import tempfile

# Try to import optional dependencies
try:
    import pymysql
    MYSQL_AVAILABLE = True
except ImportError:
    MYSQL_AVAILABLE = False
    print("Warning: pymysql not installed. Database features disabled.")

# Import Wiegand format registry
try:
    from formats.wiegand_formats import FormatRegistry, init_registry
    FORMAT_REGISTRY_AVAILABLE = True
except ImportError:
    FORMAT_REGISTRY_AVAILABLE = False
    print("Warning: Format registry not available. Using legacy format support.")

# Optional character LCD at the door (lcd.py). Missing module = no display.
try:
    from lcd import create_lcd
    LCD_AVAILABLE = True
except ImportError:
    LCD_AVAILABLE = False

# Version
def _read_version():
    """Read version from VERSION file, fallback to 'unknown'"""
    version_file = os.path.join(os.environ.get('PIDOORS_DIR', '/opt/pidoors'), 'VERSION')
    try:
        with open(version_file, 'r') as f:
            return f.read().strip()
    except Exception:
        return 'unknown'

VERSION = _read_version()

# Configuration
DEBUG_MODE = False
INSTALL_DIR = os.environ.get('PIDOORS_DIR', '/opt/pidoors')
CONF_DIR = os.path.join(INSTALL_DIR, 'conf') + '/'
CACHE_DIR = os.path.join(INSTALL_DIR, 'cache') + '/'
MASTER_CARDS_FILE = os.path.join(CACHE_DIR, 'master_cards.json')
_OLD_MASTER_CARDS_FILE = os.path.join(CONF_DIR, 'master_cards.json')
CUSTOM_FORMATS_FILE = os.path.join(CONF_DIR, 'formats.json')
SSL_CA_PATH = os.path.join(CONF_DIR, 'ca.pem')
SSL_CA_STALE_PATH = os.path.join(CONF_DIR, 'ca.pem.stale')
CACHE_DURATION = 86400  # 24 hours in seconds
# Default heartbeat fallback. The EFFECTIVE interval is read at runtime from the
# server-provided door/global settings (see get_heartbeat_interval) so it stays
# in sync with the server's offline threshold (3x heartbeat_interval) and
# healthy doors don't flap offline. This value is only used until settings load.
HEARTBEAT_INTERVAL = 300  # seconds (fallback only)
DB_RETRY_INTERVAL = 30  # seconds
# Master cards are persistent emergency credentials. If the DB is unreachable we
# fail OPEN on them (emergency access must work during an outage) — but only for
# a BOUNDED window. A master card that has not been re-verified against the DB
# within this many days is treated as expired locally, so an attacker who
# induces a prolonged outage cannot keep using a card that was meant to be
# revoked. Explicit revocations (seen while online) take effect immediately.
MASTER_CARD_MAX_STALE_DAYS = 7

# Global variables
zone = None
config = None
last_card = None
zone_by_pin = {}
repeat_read_count = 0
repeat_read_timeout = time.time()
db_connected = False
last_db_attempt = 0
ssl_mode = None  # None = not yet connected, 'tls' = verified TLS (the only allowed mode)
local_cache = {}
cache_last_sync = 0
heartbeat_thread = None
command_poll_thread = None
running = True
door_unlocked = False  # Real-time lock state tracking
master_cards = {}  # Persistent master cards (never expire)
format_registry = None  # Wiegand format registry
door_sensor_open = None  # Current door sensor state (None/True/False)
current_sensor_pin = None  # Currently active door sensor GPIO pin

# Gate mode state
gate_enabled = False           # True if this door is configured as a gate
gate_state = 'idle'            # idle / opening / closing / stopped / open / closed
gate_held = False              # True = ignore movement commands until released
gate_config = {}               # Loaded from DB doors.gate_config
gate_active_output = None      # Currently active output ('open'/'close'/'stop'/None)
gate_stop_event = None         # threading.Event used to interrupt active output
gate_input_pins = {}           # Map of pin number -> input name ('open'/'stop'/'close'/'clearance')
gate_output_pins = {}          # Map of output name -> pin number
gate_tap_state = {}            # Per-input tap counter state: {name: {'count':n, 'expires':t}}
gate_clearance_pin = None      # Optional clearance sensor GPIO pin (None = not configured)
gate_clearance_clear = True    # True = path is clear, False = something is blocking
gate_auto_close_timer = None   # threading.Timer for auto-close countdown

# Reader LED state (from the door's status_led_config). A door that has never
# been given an LED config gets the historical bicolor pair: GPIO 25 green,
# GPIO 22 red, active high.
led_green_pin = None           # Lit while the door is open (single-line readers use only this)
led_red_pin = None             # Optional second line, lit while the door is closed
led_active = 1                 # Polarity for both lines: 1 = active high, 0 = active low
led_anim_gen = 0               # Bumped to cancel an in-flight pulse/flash animation
LEGACY_LED_CFG = {'enabled': True, 'green_pin': 25, 'red_pin': 22, 'active_high': True}

# Door LCD state (see lcd.py). lcd is None when no display is configured.
lcd = None
lcd_lock = threading.Lock()
lcd_revert_timer = None        # Timer that returns the display to idle after a message
lcd_refresh_started = False    # Idle refresh thread started once per process
lcd_applied_cfg = None         # lcd_config dict last applied (skip re-init when unchanged)

# Per-key Wiegand keypad defaults (4-bit / 8-bit "one frame per keypress" mode).
# Overridable per reader in config.json with "pin_timeout" / "pin_max_length".
KEYPAD_PIN_TIMEOUT = 5.0       # Seconds between keys before a partial PIN is discarded
KEYPAD_PIN_MAX_LENGTH = 10     # 2^32-1 fits in 10 digits (34-bit frame)

# Master card hold settings (loaded from DB settings)
master_scans_hold_open = 3
master_scans_release_hold = 1

# Unlock schedule (doors.schedule_id) — hold the door/gate open during the
# schedule's hours and relock when the window ends. Evaluated by schedule_loop().
SCHEDULE_CHECK_INTERVAL = 15   # seconds between schedule evaluations
schedule_state = {
    'in_window': None,     # last evaluated in-window result (None = not evaluated yet)
    'hold_active': False,  # True while the current hold was applied by the schedule
}

# Thread locks for shared state
state_lock = threading.Lock()  # For db_connected, last_db_attempt, cache_last_sync
cache_lock = threading.Lock()  # For local_cache access
sync_lock = threading.Lock()   # Serializes sync_cache_from_server (hourly vs. push-triggered)
schedule_eval_lock = threading.Lock()  # Serializes unlock-schedule evaluation (loop vs. post-sync)
card_lock = threading.Lock()   # For last_card, repeat_read_count, repeat_read_timeout
master_lock = threading.Lock() # For master_cards access
wiegand_lock = threading.Lock() # For legacy Wiegand stream access
gate_lock = threading.Lock()   # For gate state mutations


def _try_db_connect(kwargs):
    """Attempt a verified-TLS database connection.

    SECURITY: This is access-control software. The DB carries card/credential
    data and the access decisions derived from it, so the channel MUST be
    encrypted AND the server certificate MUST be verified against a CA that was
    provisioned out-of-band (conf/ca.pem). We therefore NEVER pass ssl_disabled
    and NEVER fall back to cleartext — an un-verifiable DB connection is a hard
    failure (treated as offline) so we fail SECURE rather than leaking
    credentials over the wire.
    """
    kw = dict(kwargs)
    # ssl_verify_cert / ssl_verify_identity require pymysql >= 1.0; harmless on
    # older versions where the 'ssl' dict alone enables verification.
    kw['ssl'] = {'ca': SSL_CA_PATH}
    kw['ssl_verify_cert'] = True
    kw['ssl_verify_identity'] = True
    return pymysql.connect(**kw)


def get_db_connection(timeout=5):
    """
    Create a verified-TLS database connection, or fail closed.

    A CA certificate (conf/ca.pem) MUST have been provisioned out-of-band
    (during install/provisioning over a trusted channel). It is NEVER fetched
    over plaintext HTTP at runtime — doing so would let anyone on the path
    inject their own CA and MITM the credential/access-decision traffic.

    If conf/ca.pem is missing/empty, or the verified-TLS connection fails for
    any reason, this returns None (caller treats the DB as offline and uses the
    local cache). There is NO cleartext / ssl_disabled fallback.
    """
    global ssl_mode

    if not MYSQL_AVAILABLE:
        return None

    zone_config = config.get(zone, {})
    sqladdr = zone_config.get("sqladdr")
    sqluser = zone_config.get("sqluser")
    sqlpass = zone_config.get("sqlpass")
    sqldb = zone_config.get("sqldb")

    if not all([sqladdr, sqluser, sqlpass, sqldb]):
        return None

    # Hard requirement: a provisioned CA must exist. Without it we cannot verify
    # the server, so we refuse to connect (offline) rather than fall back to an
    # unencrypted or unverified channel.
    if not (os.path.isfile(SSL_CA_PATH) and os.path.getsize(SSL_CA_PATH) > 0):
        report(f"TLS: no provisioned CA at {SSL_CA_PATH} — refusing DB connection "
               f"(provision ca.pem out-of-band). Treating DB as offline.")
        return None

    kwargs = {
        'host': sqladdr,
        'user': sqluser,
        'password': sqlpass,
        'database': sqldb,
        'connect_timeout': timeout,
    }

    try:
        conn = _try_db_connect(kwargs)
        if ssl_mode != 'tls':
            ssl_mode = 'tls'
            report("TLS: connected to DB with verified certificate")
        return conn
    except Exception as e:
        # Any failure (including TLS/cert errors) is a HARD failure. We do not
        # downgrade to cleartext. Propagate so callers handle it as DB-down.
        debug(f"TLS: verified DB connection failed: {e}")
        raise


def get_local_ip():
    """Get the local IP address of this device"""
    try:
        s = socket.socket(socket.AF_INET, socket.SOCK_DGRAM)
        s.connect(('1.1.1.1', 53))
        ip = s.getsockname()[0]
        s.close()
        return ip
    except Exception:
        return '127.0.0.1'


myip = '127.0.0.1'


def initialize():
    """Initialize the access control system"""
    global running, format_registry, myip
    running = True

    # Detect local IP (network should be ready by now, unlike module load time)
    myip = get_local_ip()

    GPIO.setmode(GPIO.BCM)
    GPIO.setwarnings(False)
    syslog.openlog("accesscontrol", syslog.LOG_PID, syslog.LOG_AUTH)

    report("Initializing PiDoors Access Control")

    # Ensure cache directory exists
    os.makedirs(CACHE_DIR, exist_ok=True)

    # Load configurations
    read_configs()

    # Initialize format registry with optional custom formats
    if FORMAT_REGISTRY_AVAILABLE:
        custom_formats = CUSTOM_FORMATS_FILE if os.path.exists(CUSTOM_FORMATS_FILE) else None
        format_registry = init_registry(custom_formats)
        supported = format_registry.get_supported_lengths()
        report(f"Wiegand format registry initialized: {supported}")
    else:
        report("Using legacy Wiegand format support (26/34-bit only)")

    # Load local cache and persistent master cards
    load_cache()
    load_master_cards()

    # Setup GPIO
    setup_output_GPIOs()
    setup_readers()
    setup_door_sensor()
    setup_rex_button()

    # Initial door state: locked
    lock_door()

    # Catch exit signals
    signal.signal(signal.SIGINT, cleanup)
    signal.signal(signal.SIGTERM, cleanup)
    signal.signal(signal.SIGHUP, rehash)
    signal.signal(signal.SIGUSR2, rehash)
    signal.signal(signal.SIGWINCH, toggle_debug)

    # Start heartbeat thread
    start_heartbeat_thread()

    # Start command poll thread (lightweight fast-poll for remote unlock)
    start_command_poll_thread()

    # Start unlock schedule thread (holds the door open during doors.schedule_id hours)
    start_schedule_thread()

    # Start push listener (HTTPS server for instant commands from server)
    start_push_listener()

    # Sync cache from server
    sync_cache_from_server()

    report(f"{zone} access control is online (IP: {myip}, version: {VERSION})")


def report(subject):
    """Log to syslog and debug output"""
    syslog.syslog(subject)
    debug(subject)


def debug(message):
    """Print debug message if debug mode is enabled"""
    if DEBUG_MODE:
        timestamp = datetime.now().strftime('%Y-%m-%d %H:%M:%S')
        print(f"[{timestamp}] {message}")


def _reseed_reader_runtime_keys():
    """Re-add the per-reader runtime keys that setup_readers injects.

    read_configs() reloads config.json from disk, which REPLACES the global
    `config` dict with fresh reader dicts that lack the runtime keys
    setup_readers added ("stream", "timer", "name", "unlocked"). Without these,
    the next Wiegand pulse KeyErrors inside the GPIO callback (data_pulse /
    wiegand_stream_done) and kills the shared event thread. Re-seed them so the
    readers keep working after a SIGHUP rehash. Pins are unchanged, so we do NOT
    re-register GPIO edge detection here."""
    for name in config:
        if name == "<zone>" or not isinstance(config[name], dict):
            continue
        reader = config[name]
        if reader.get("d0") and reader.get("d1"):
            reader.setdefault("stream", "")
            reader.setdefault("timer", None)
            reader.setdefault("pin_buffer", "")
            reader.setdefault("pin_timer", None)
            reader["name"] = name
            reader.setdefault("unlocked", False)


def rehash(sig=None, frame=None):
    """Reload configurations and sync cache"""
    report("Rehashing configuration")
    read_configs()
    # read_configs replaced the global config; restore reader runtime keys so the
    # Wiegand GPIO callbacks don't KeyError on the next scan.
    _reseed_reader_runtime_keys()
    sync_cache_from_server()


def toggle_debug(sig=None, frame=None):
    """Toggle debug mode on/off"""
    global DEBUG_MODE
    DEBUG_MODE = not DEBUG_MODE
    debug(f"Debug mode: {'enabled' if DEBUG_MODE else 'disabled'}")


def read_configs():
    """Load configuration files"""
    global zone, config
    try:
        jzone = load_json(CONF_DIR + "zone.json")
        config = load_json(CONF_DIR + "config.json")
        zone = jzone.get("zone", "default")
        debug(f"Configuration loaded for zone: {zone}")
    except Exception as e:
        report(f"Error loading configuration: {e}")
        sys.exit(1)


def load_json(filename):
    """Load and parse a JSON file"""
    with open(filename, 'r') as f:
        return json.load(f)


def save_json(filename, data):
    """Save data to a JSON file ATOMICALLY.

    Write to a temp file in the SAME directory, flush + fsync it to durable
    storage, then os.replace() it over the target. os.replace is atomic on the
    same filesystem, so a power loss mid-write leaves either the old complete
    file or the new complete file — never a truncated one that load_* would
    reset to {} (which, for the master-card / cache files, means silently
    losing offline access data)."""
    dir_name = os.path.dirname(filename) or '.'
    # Temp file in the same dir guarantees os.replace stays on one filesystem.
    fd, tmp_path = tempfile.mkstemp(prefix='.tmp-', dir=dir_name)
    try:
        with os.fdopen(fd, 'w') as f:
            json.dump(data, f, indent=2, default=str)
            f.flush()
            os.fsync(f.fileno())
        os.replace(tmp_path, filename)
    except Exception:
        # Clean up the temp file on any failure so we don't leave litter behind.
        try:
            os.remove(tmp_path)
        except OSError:
            pass
        raise


# ============================================================
# LOCAL CACHE MANAGEMENT (24-hour offline capability)
# ============================================================

def get_cache_file():
    """Get the path to the cache file for this zone"""
    return os.path.join(CACHE_DIR, f"{zone}_access_cache.json")


def load_cache():
    """Load the local access cache from disk"""
    global local_cache, cache_last_sync
    cache_file = get_cache_file()

    try:
        if os.path.exists(cache_file):
            with open(cache_file, 'r') as f:
                cache_data = json.load(f)
                cache_last_sync = cache_data.get('sync_time', 0)

                # New flat format has 'schedules' at top level alongside 'cards'
                if 'schedules' in cache_data:
                    local_cache = cache_data
                else:
                    # Legacy format: full cache nested under 'cards' key
                    local_cache = cache_data.get('cards', {})

                # Check if cache is still valid (within 24 hours)
                if time.time() - cache_last_sync > CACHE_DURATION:
                    report("Local cache expired (>24 hours old)")
                else:
                    card_count = len(local_cache.get('cards', {}))
                    report(f"Loaded {card_count} cards from local cache")
    except Exception as e:
        report(f"Error loading cache: {e}")
        local_cache = {}
        cache_last_sync = 0


def save_cache():
    """Save the local access cache to disk"""
    global cache_last_sync
    cache_file = get_cache_file()

    try:
        # Save local_cache structure (cards, schedules, holidays, door_settings)
        # with metadata at the same level
        cache_data = dict(local_cache)
        cache_data['zone'] = zone
        cache_data['sync_time'] = time.time()
        cache_data['sync_datetime'] = datetime.now().isoformat()
        save_json(cache_file, cache_data)
        cache_last_sync = cache_data['sync_time']
        debug(f"Cache saved with {len(local_cache.get('cards', {}))} cards")
    except Exception as e:
        report(f"Error saving cache: {e}")


# ============================================================
# MASTER CARD MANAGEMENT (Persistent - Never Expires)
# ============================================================

def load_master_cards():
    """
    Load master cards from persistent storage.
    Master cards never expire - they are used for emergency access.
    """
    global master_cards

    try:
        # Migrate from old location (conf/) to new location (cache/) if needed
        if not os.path.exists(MASTER_CARDS_FILE) and os.path.exists(_OLD_MASTER_CARDS_FILE):
            try:
                import shutil
                shutil.copy2(_OLD_MASTER_CARDS_FILE, MASTER_CARDS_FILE)
                report("Migrated master_cards.json from conf/ to cache/")
            except Exception as e:
                report(f"Could not migrate master_cards.json: {e}")

        if os.path.exists(MASTER_CARDS_FILE):
            with open(MASTER_CARDS_FILE, 'r') as f:
                data = json.load(f)
                with master_lock:
                    master_cards = data.get('cards', {})
                card_count = len(master_cards)
                if card_count > 0:
                    report(f"Loaded {card_count} master cards from persistent storage")
    except Exception as e:
        report(f"Error loading master cards: {e}")
        with master_lock:
            master_cards = {}


def save_master_cards():
    """Save master cards to persistent storage"""
    try:
        with master_lock:
            data = {
                'last_sync': datetime.now().isoformat(),
                'cards': dict(master_cards)
            }
        save_json(MASTER_CARDS_FILE, data)
        debug(f"Master cards saved: {len(master_cards)} cards")
    except Exception as e:
        report(f"Error saving master cards: {e}")
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

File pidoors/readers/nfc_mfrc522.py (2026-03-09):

"""
MFRC522 NFC/RFID Reader Module
PiDoors Access Control System

MFRC522 NFC reader support over SPI interface.
Supports reading Mifare Classic, Ultralight, and other ISO14443A cards.

Requires:
  - spidev package
  - RPi.GPIO for reset pin
"""

import threading
import time
from typing import Dict, Any, Optional, List
from enum import IntEnum

from .base import BaseReader, CardRead, ReaderType, ReaderStatus

# Try to import SPI library
try:
    import spidev
    SPI_AVAILABLE = True
except ImportError:
    SPI_AVAILABLE = False

# Try to import GPIO library
try:
    import RPi.GPIO as GPIO
    GPIO_AVAILABLE = True
except ImportError:
    GPIO_AVAILABLE = False


class MFRC522Register(IntEnum):
    """MFRC522 register addresses"""
    # Command and Status
    COMMAND = 0x01
    COMIEN = 0x02
    DIVIEN = 0x03
    COMIRQ = 0x04
    DIVIRQ = 0x05
    ERROR = 0x06
    STATUS1 = 0x07
    STATUS2 = 0x08
    FIFODATA = 0x09
    FIFOLEVEL = 0x0A
    WATERLEVEL = 0x0B
    CONTROL = 0x0C
    BITFRAMING = 0x0D
    COLL = 0x0E

    # Command
    MODE = 0x11
    TXMODE = 0x12
    RXMODE = 0x13
    TXCONTROL = 0x14
    TXASK = 0x15
    TXSEL = 0x16
    RXSEL = 0x17
    RXTHRESHOLD = 0x18
    DEMOD = 0x19
    MFTX = 0x1C
    MFRX = 0x1D
    SERIALSPEED = 0x1F

    # Configuration
    CRCRESULTM = 0x21
    CRCRESULTL = 0x22
    MODWIDTH = 0x24
    RFCFG = 0x26
    GSN = 0x27
    CWGSP = 0x28
    MODGSP = 0x29
    TMODE = 0x2A
    TPRESCALER = 0x2B
    TRELOADH = 0x2C
    TRELOADL = 0x2D
    TCOUNTERH = 0x2E
    TCOUNTERL = 0x2F

    # Test
    TESTSEL1 = 0x31
    TESTSEL2 = 0x32
    TESTPINEN = 0x33
    TESTPINVALUE = 0x34
    TESTBUS = 0x35
    AUTOTEST = 0x36
    VERSION = 0x37
    ANALOGTEST = 0x38
    TESTDAC1 = 0x39
    TESTDAC2 = 0x3A
    TESTADC = 0x3B


class MFRC522Command(IntEnum):
    """MFRC522 commands"""
    IDLE = 0x00
    MEM = 0x01
    GENERATE_RANDOM_ID = 0x02
    CALCCRC = 0x03
    TRANSMIT = 0x04
    NOCMDCHANGE = 0x07
    RECEIVE = 0x08
    TRANSCEIVE = 0x0C
    MFAUTHENT = 0x0E
    SOFTRESET = 0x0F


class PICommand(IntEnum):
    """ISO14443A commands"""
    REQIDL = 0x26
    REQALL = 0x52
    ANTICOLL1 = 0x93
    ANTICOLL2 = 0x95
    ANTICOLL3 = 0x97
    SELECT1 = 0x93
    SELECT2 = 0x95
    SELECT3 = 0x97
    AUTHENT1A = 0x60
    AUTHENT1B = 0x61
    READ = 0x30
    WRITE = 0xA0
    DECREMENT = 0xC0
    INCREMENT = 0xC1
    RESTORE = 0xC2
    TRANSFER = 0xB0
    HALT = 0x50


class MFRC522Reader(BaseReader):
    """
    MFRC522 NFC/RFID card reader over SPI.

    Configuration options:
        spi_bus: SPI bus number (default: 0)
        spi_device: SPI device/chip select (default: 0)
        spi_speed: SPI speed in Hz (default: 1000000)
        reset_pin: GPIO pin for hardware reset (default: 25)
        poll_interval: Card polling interval in seconds (default: 0.2)
        debounce_time: Time to wait before reading same card again (default: 2.0)
        antenna_gain: RF gain 0-7 (default: 4)

    Example config:
        {
            "spi_bus": 0,
            "spi_device": 0,
            "reset_pin": 25,
            "poll_interval": 0.2,
            "antenna_gain": 4
        }
    """

    MAX_LEN = 16

    def __init__(self, name: str, config: Dict[str, Any], on_card_read=None):
        super().__init__(name, config, on_card_read)

        self.poll_interval: float = 0.2
        self.debounce_time: float = 2.0

        self._spi = None
        self._reset_pin: Optional[int] = None
        self._running: bool = False
        self._poll_thread: Optional[threading.Thread] = None
        self._last_card: Optional[str] = None
        self._last_card_time: float = 0

    @staticmethod
    def get_reader_type() -> ReaderType:
        return ReaderType.NFC_MFRC522

    def initialize(self) -> bool:
        """Initialize the MFRC522 reader"""
        self.status = ReaderStatus.INITIALIZING

        if not SPI_AVAILABLE:
            self.set_error("spidev not available - install with: pip install spidev")
            return False

        if not GPIO_AVAILABLE:
            self.set_error("RPi.GPIO not available")
            return False

        bus = self.get_config_value('spi_bus', 0)
        device = self.get_config_value('spi_device', 0)
        speed = self.get_config_value('spi_speed', 1000000)
        self._reset_pin = self.get_config_value('reset_pin', 25)
        self.poll_interval = self.get_config_value('poll_interval', 0.2)
        self.debounce_time = self.get_config_value('debounce_time', 2.0)
        antenna_gain = self.get_config_value('antenna_gain', 4)

        try:
            # Setup GPIO for reset
            GPIO.setmode(GPIO.BCM)
            GPIO.setup(self._reset_pin, GPIO.OUT)
            GPIO.output(self._reset_pin, GPIO.HIGH)

            # Open SPI
            self._spi = spidev.SpiDev()
            self._spi.open(bus, device)
            self._spi.max_speed_hz = speed
            self._spi.mode = 0

            # Reset and initialize
            self._hard_reset()
            self._soft_reset()

            # Timer configuration
            self._write_register(MFRC522Register.TMODE, 0x8D)
            self._write_register(MFRC522Register.TPRESCALER, 0x3E)
            self._write_register(MFRC522Register.TRELOADL, 30)
            self._write_register(MFRC522Register.TRELOADH, 0)

            # Force 100% ASK modulation
            self._write_register(MFRC522Register.TXASK, 0x40)

            # Default mode
            self._write_register(MFRC522Register.MODE, 0x3D)

            # Set antenna gain
            self._set_antenna_gain(antenna_gain)

            # Turn on antenna
            self._antenna_on()

            # Verify chip version
            version = self._read_register(MFRC522Register.VERSION)
            if version not in [0x91, 0x92]:
                self.set_error(f"Unknown MFRC522 version: {version:#x}")
                return False

            self.status = ReaderStatus.READY
            return True

        except Exception as e:
            self.set_error(f"Initialization failed: {e}")
            return False

    def start(self) -> bool:
        """Start reading cards"""
        if self.status != ReaderStatus.READY:
            if not self.initialize():
                return False

        self._running = True
        self._poll_thread = threading.Thread(target=self._poll_loop, daemon=True)
        self._poll_thread.start()

        self.status = ReaderStatus.READING
        return True

    def stop(self) -> bool:
        """Stop reading and release resources"""
        self._running = False

        if self._poll_thread and self._poll_thread.is_alive():
            self._poll_thread.join(timeout=2.0)

        # Turn off antenna
        try:
            self._antenna_off()
        except Exception:
            pass

        if self._spi:
            try:
                self._spi.close()
            except Exception:
                pass
            self._spi = None
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

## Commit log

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2026-01-10 Major system upgrade
    This commit represents a complete overhaul of PiDoors to bring it to industrial/retail standards with comprehensive security, offline capability, and modern features.
    SECURITY ENHANCEMENTS:
    - Replaced all SQL queries with PDO prepared statements to prevent SQL injection
    - Upgraded password hashing from MD5 to bcrypt with automatic migration
    - Implemented CSRF token protection on all forms
    - Added comprehensive input validation and sanitization
    - Implemented secure session handling with timeout and regeneration
    - Enforced password strength requirements
    DATABASE SCHEMA:
    - Created access_schedules table for time-based access control
    - Created access_groups table for permi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
    [pidoors.py]
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2026-01-10 Security updates and bug fixes
    Python Controller (pidoors.py):
    - Fix path configuration to use PIDOORS_DIR environment variable
    - Remove unused hashlib import and dead active() function
    - Add thread locks (state_lock, cache_lock, card_lock) for thread safety
    - Fix database connection leaks with try/finally in all functions
    - Make schedule checks fail-secure (deny when unknown)
    - Add cache_lock to all cache read operations
    - Add error handling for date/time parsing with fail-secure defaults
    Systemd Service:
    - Fix conflicting ReadWritePaths/ReadOnlyPaths settings
    PHP Security:
    - Remove legacy mysqli code from db_connection.php
    - Add CSRF protection to logout.php
    - Fix login.php to use config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
    [pidoors.py]
2026-01-10 Feature: Add multi-reader support and persistent master cards
    Expand card reader and card type support with modular reader architecture:
    Reader Modules:
    - Add reader abstraction layer with BaseReader class and ReaderFactory
    - Wiegand: Support all standard formats (26, 32, 34, 35, 36, 37, 48-bit)
    - OSDP: RS-485 encrypted reader support with AES-128 Secure Channel
    - NFC PN532: I2C/SPI NFC reader for Mifare cards
    - NFC MFRC522: SPI NFC reader for Mifare cards
    Wiegand Format Registry:
    - Centralized format definitions with parity validation
    - Custom format support via formats.json configuration
    - Auto-detection of card bit length
    Master Card System (Critical Fix):
    - Persistent storage in maste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
    [base.py, nfc_mfrc522.py, nfc_pn532.py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]
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2026-01-10 PCB: Replace outdated gerbers with professional v2.0 specification
    Remove old KiCad gerber files (basic 2020 design) and replace with
    comprehensive PCB specification document for professional manufacturing.
    New PCB_SPECIFICATION.md includes:
    - Multi-reader support (Wiegand, OSDP RS-485, PN532, MFRC522)
    - Complete protection circuits (ESD, surge, overcurrent, reverse polarity)
    - Optically isolated door sensor input
    - Protected relay output with flyback diode
    - Full GPIO mapping matching PiDoors v2.2 software
    - DC-DC power supply design (9-24V input)
    - Detailed BOM with part numbers and cost estimates
    - PCB layout guidelines and design rules
    - Testing procedures for production validation
    - Ra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
    [pihidscan-B_Cu.gbr, pihidscan-B_Mask.gbr, pihidscan-B_Paste.gbr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]
2026-01-10 PCB: Add KiCad project files for PiDoors HAT v2.0
    Complete KiCad 7/8 project for professional PCB manufacturing:
    Project Files:
    - pidoors-hat.kicad_pro - Project configuration
    - pidoors-hat.kicad_sch - Schematic placeholder
    - pidoors-hat.kicad_pcb - PCB with HAT outline and mounting holes
    - pidoors-hat.net - Complete netlist (50+ components, 44 nets)
    Manufacturing Files:
    - pidoors-hat-bom.csv - Bill of Materials with LCSC part numbers
    - pidoors-hat-cpl.csv - Component Placement List for SMT assembly
    Features:
    - Pi HAT form factor (65mm x 56.5mm)
    - M2.5 mounting holes at standard positions
    - Support for all reader types (Wiegand, OSDP, NFC)
    - Full protection circuits (ESD, surge, reverse p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
    [pidoors-hat-bom.csv, pidoors-hat.kicad_pcb, pidoors-hat.kicad_sch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]
2026-01-10 PCB: Complete routing and generate Gerber manufacturing files
    - Fix GPIO discrepancy: LED Granted now uses GPIO 25 (was GPIO 5)
    - Fix README: Relay uses GPIO 18 (was incorrectly listed as GPIO 17)
    - Complete KiCad schematic with all component symbols and connections
    - Route PCB with power traces (0.5mm) and signal traces (0.25mm)
    - Add ground plane on bottom copper layer
    - Generate Gerber files in RS-274X format for JLCPCB
    - Generate Excellon drill files (PTH and NPTH)
    - Add manufacturing checklist with ordering instructions
    - Add gerber generation script for KiCad 8.x
    [pidoors-hat-B_Cu.gbl, pidoors-hat-B_Mask.gbs, pidoors-hat-B_SilkS.gbo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]
2026-01-10 Bug fixes
    Python door controller (pidoors.py):
    - Fix #1: Add safe .get() access in rex_button_pressed() to prevent KeyError
    - Fix #2: Add safe .get() access in open_door() to prevent KeyError
    - Fix #3: Add state_lock when accessing cache_last_sync in heartbeat_loop()
    - Fix #4: Replace bare except with explicit Exception in cleanup()
    Database schema (database_migration.sql):
    - Fix #5: Change user_id column to varchar(32) in door_events table
    - Fix #5: Change user_id to varchar(32) and facility to varchar(16) in master_cards
    All GPIO mappings verified consistent across software and PCB design.
    All PHP files verified secure (CSRF, PDO prepared statements, input sanitization).
    [pidoors.py]
2026-01-10 Fix race condition in log file operations
    - Add file locking with fcntl.flock() to prevent concurrent access
    corruption in log_access() and log_door_event() functions
    - Add graceful JSON corruption handling with automatic recovery
    - Import fcntl module for file locking support
    - Medium: Race condition when multiple threads write to log files
    - Low: JSON corruption not handled gracefully
    [pidoors.py]
2026-01-10 Fix thread safety in legacy Wiegand handling
    Add wiegand_lock to protect reader stream and timer access in the
    legacy Wiegand code path. The GPIO interrupt callbacks (data_pulse)
    could race with the timer thread (wiegand_stream_done), potentially
    corrupting the bit stream.
    Changes:
    - Add wiegand_lock for legacy Wiegand stream synchronization
    - Inline kick_timer() into data_pulse() for atomic operations
    - Process validate_bits() outside lock to avoid holding lock during
    card validation
    Note: The readers/wiegand.py module already has proper thread safety
    with _stream_lock. This fix addresses only the legacy fallback code.
    [pidoors.py]
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2026-01-10 Fix zone matching logic
    Fix HIGH severity security issue where substring matching in zone access
    checks could allow unauthorized access. For example, a user with access
    to zone "main" could potentially access the "maintenance" zone.
    Python changes (pidoors.py):
    - Changed SQL query to use FIND_IN_SET() instead of LIKE '%zone%'
    - Changed cache lookup to use doors.split(',') for proper list matching
    - Changed database lookup to use proper comma-delimited list checking
    PHP changes (addcard.php, editcard.php, cards.php):
    - Changed door storage from space-separated to comma-separated format
    - Ensures consistency between Python and PHP modules
    Test changes (conftest.py):
    - Updated test fixtures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
    [pidoors.py]
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2026-02-28 Convert add forms to modals, add door auto-registration, rewrite install script
    - Convert all "add" forms to Bootstrap modals (doors, cards, groups,
    schedules, holidays, panel users) instead of separate pages or
    side panels. Edit actions auto-open the modal with pre-filled data.
    - Remove redundant "Add Users" sidebar link from header.php
    - Fix DataTables "Incorrect column count" error by removing colspan
    empty-state row from logs.php (DataTables handles empty tables)
    - Add auto-registration to door controller heartbeat: if a door
    doesn't exist in the database, the first heartbeat creates it
    with name, IP, status, reader type from client config
    - Rewrite install.sh with guided step-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
    [pidoors.py]
2026-02-28 Fix GPIO setup order crash and mysql_secure_installation on Bookworm
    - Fix RuntimeError in pidoors.py: LED GPIO pins (25, 22) were used by
    lock_door() before being set up as OUTPUT. Moved LED setup before
    lock_door() call in setup_output_GPIOs().
    - Fix install.sh: detect mariadb-secure-installation (Bookworm) vs
    mysql_secure_installation (Bullseye) instead of hardcoding the old name.
    - Auto-configure MariaDB bind-address to 0.0.0.0 during server install
    so remote door controllers can connect.
    - Bump install script version to 2.3.1.
    [pidoors.py]
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2026-02-28 Fix GPIO on Bookworm+: use rpi-lgpio instead of RPi.GPIO
    RPi.GPIO 0.7.1 add_event_detect is broken on Debian 12+/13+.
    Install script now detects Bookworm+ and uses the system rpi-lgpio
    (drop-in replacement) instead of pip-installing RPi.GPIO into the venv.
    [pidoors.py]
2026-02-28 Fix lgpio temp file issue: use RuntimeDirectory for writable workdir
    lgpio (used by rpi-lgpio on Debian 12+) creates notification pipe files
    in the working directory on import. When WorkingDirectory was /opt/pidoors
    the service user couldn't write there, causing startup failure.
    - systemd service: use RuntimeDirectory=pidoors with WorkingDirectory=/run/pidoors
    - pidoors.py: add /opt/pidoors to sys.path before importing RPi.GPIO so
    local imports (formats, readers) still resolve from the install dir
    [pidoors.py]
2026-02-28 Fix door IP showing 127.0.0.1: detect IP after network is ready
    get_local_ip() was called at module load time before the network was up
    at boot, causing it to fall back to 127.0.0.1 permanently. Now:
    - IP detection runs in initialize() after systemd network.target
    - Heartbeat loop retries detection if still 127.0.0.1
    [pidoors.py]
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2026-03-05 Fix fresh install failures and read-only master_cards crash
    - Commit database_migration.sql to git (fresh installs were missing all tables)
    - Harden install.sh: fallback paths for migration SQL, hard error if missing,
    post-migration table verification
    - Fix master_cards.json write crash: move from conf/ (read-only) to cache/
    with auto-migration from old location
    - Fix pidoors.service: use network-online.target, remove mysql.service dep,
    remove redundant ReadOnlyPaths
    - Add service file update to pidoors-update.sh with daemon-reload
    - Add daily_scan_limit to cards.php add modal and editcard.php
    - Add master_card + daily_scan_limit to both INSERT and UPDATE queries
    - Create server-update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
    [pidoors.py]
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2026-03-05 Fix 7 bugs from system audit, secure password handling
    - export_logs.php: fix rowCount() crash on fetchAll() array
    - pidoors.py: fix cache save/load structure mismatch and card count reporting
    - pidoors.py: add MYSQL_AVAILABLE guard in try_database_lookup()
    - pidoors.py: run unlock_briefly() in daemon thread to avoid blocking GPIO callbacks
    - install.sh: use MYSQL_PWD env var and stdin for password handling
    - server-update.sh: use MYSQL_PWD env var for password handling
    - update.php: temp dir 0700 permissions with mkdir failure check
    - README.md: update version badge to track current version
    [pidoors.py]
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2026-03-05 Add remote door unlock from web UI and fix update trigger loop
    - Remote unlock button on door cards (online doors only) with audit logging
    - Lightweight command poll loop on controller checks for unlock requests every few seconds
    - Per-door configurable poll interval (1-60s, default 3) on edit door page
    - Real-time lock state tracking (door_unlocked global) replaces static config value
    - Fix: clear update_requested flag before triggering update to prevent re-trigger loop
    [pidoors.py]
2026-03-06 Add TLS encryption for database connections (v2.6.0)
    Encrypt all controller-to-server MySQL traffic with TLS to prevent
    credential sniffing and unauthorized database access on the network.
    - Centralize 6 duplicate pymysql.connect() calls into get_db_connection()
    helper with automatic TLS when ca.pem exists
    - Server install generates self-signed CA + server cert for MariaDB
    - Controller install auto-downloads CA cert from server via HTTP
    - PHP web UI supports optional TLS via sql_ssl_ca config key
    - Update pidoors-update.sh inline Python to use TLS
    - Fully backward compatible: no ca.pem = unencrypted (existing installs)
    [pidoors.py]
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2026-03-07 Add email notifications and self-healing TLS (v2.7.0)
    Email notifications: SMTP sender, settings UI with test button,
    cron script for door offline/online alerts, repeated access denied
    alerts, and daily summary reports. Falls back to PHP mail() when
    no SMTP configured.
    Self-healing TLS: controller now auto-recovers from certificate
    mismatches by fetching fresh ca.pem from server, falling back to
    plain connection if server has no TLS. Prevents the host-blocked
    scenario where repeated SSL failures exhaust max_connect_errors.
    [pidoors.py]
2026-03-08 Self-healing schema, clear stale update status, auto-migrate on version change
    - editdoor.php: auto-adds missing columns and retries on Unknown column error
    - pidoors.py heartbeat: clears stale "updating" status when controller is online
    - update.php: runs database_migration.sql on page load when version changes
    [pidoors.py]
2026-03-09 v2.6.5 — Security audit, bug fixes, Docker controller files
    Security:
    - Enforce require_admin() on all management pages (cards, doors, schedules,
    groups, holidays, logs, reports, exports)
    - Block deactivated users from logging in (check active flag)
    - Add HttpOnly, SameSite, Secure flags to session cookies
    - Delete .remote credential file, add .dockerignore
    - Remove shell injection vectors in install.sh (eval → printf -v,
    parameterized admin user creation, escaped sed)
    - Harden service file fallback in install.sh (PrivateTmp, ProtectSystem)
    - Enable SMTP TLS verification by default (configurable override)
    - Add CSP and Permissions-Policy headers to Docker nginx.conf
    Bug fixes:
    - Fix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
    [mock_gpio.py, nfc_mfrc522.py, nfc_pn532.py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]
2026-03-09 v2.6.6 — Fix remote unlock not updating lock status in web UI
    Two issues caused the door to stay showing "locked" after a remote unlock:
    1. The command poll loop wrote lock state to the DB BEFORE processing the
    unlock command, so the stale locked=1 was committed on the same cycle
    that triggered the unlock. Reordered: commands are processed first,
    then lock state is read and written.
    2. unlock_briefly() spawned unlock_door() in a background thread, creating
    a race where door_unlocked was still False when the poll loop read it
    microseconds later. Now unlock_door() runs synchronously (sets GPIO and
    door_unlocked=True immediately), and only the re-lock timer runs in a
    ba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
    [pidoors.py]
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2026-03-10 v3.0.0 — React SPA migration, REST API, push communication, full audit fixes
    - React SPA frontend (TypeScript + TailwindCSS) replaces legacy PHP pages
    - Unified REST API router (api.php) with CSRF, auth, input validation
    - Push-based controller communication via HTTPS (instant commands)
    - Nginx config serves React SPA with /api/* routed to PHP-FPM
    - Install/update scripts build and deploy React SPA automatically
    - API supports both ?route= (Docker) and PATH_INFO (production nginx)
    - Heartbeat now reports api_key for push self-healing
    - Recurring holidays cached for offline enforcement
    - Door PUT validates reader_type against whitelist
    - Profile API returns properly typed integer fields
    - S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
    [pidoors.py]
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2026-03-11 v3.1.1 — Security hardening across 11 files
    IP-based rate limiting, timing-safe login, admin re-verify from DB,
    HTTPS with CA-signed certs, HSTS, CSP, nginx rate limiting, TLS
    verification for push, controller TLS 1.2+ with strong ciphers,
    SMTP CRLF prevention, mysqldump env var, LIMIT/OFFSET bound params,
    Content-Disposition sanitization, report type whitelist, mktemp fix,
    root-owned update script, CSRF auto-retry, RequireAdmin route guard,
    cert signing API endpoint, password_needs_rehash support.
    [pidoors.py]
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2026-03-20 Fix door sensor GPIO logic — grounded=closed by default, add invert toggle
    Door sensor was inverted: LOW (grounded) was treated as open when it
    should mean closed (standard NC reed switch behavior). Add _read_door_sensor()
    helper with correct default logic and door_sensor_invert DB/UI toggle for
    normally-open sensors. Controller syncs invert setting from DB on heartbeat.
    [pidoors.py]
2026-04-05 v3.1.6 — Fix heartbeat, TLS, installer, and update system
    Critical: heartbeat was completely broken (door_sensor_open missing
    global), doors never auto-registered. MariaDB TLS never enabled on
    fresh installs (grep matched commented default, wrong section header).
    Server cert missing SAN IP caused TLS verification failures. CA cert
    signing failed due to serial file permissions. Controller updates used
    system python instead of venv (no pymysql). Listener certs stuck
    self-signed after failed initial signing, breaking push commands.
    Also fixes: MySQL socket auth detection, SSL dir permissions after
    MariaDB updates, rsync deleting ca.pem, missing curl timeouts in
    update scripts, silent heartbe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
    [pidoors.py]
2026-04-05 v3.1.7 — Fix update script killed by systemd cgroup
    The update script runs inside the pidoors.service cgroup. When it
    calls systemctl stop pidoors, systemd kills all processes in the
    cgroup — including the updater. Now uses systemd-run --scope to
    launch the update in a separate scope that survives the service
    restart. Also adds systemd-run to the sudoers entry.
    [pidoors.py]
2026-04-05 v3.1.8 — Fix update script killed by systemd cgroup
    Use systemd-run to create a transient service (not --scope) for the
    update script. This fully escapes the pidoors.service cgroup so the
    updater survives systemctl stop pidoors. The --scope approach still
    ran within the cgroup lifecycle; a transient service is independent.
    Verified end-to-end: push update from server → controller downloads
    release → stops service → copies files → re-signs TLS cert →
    runs migration → restarts service → reports success. Zero user
    intervention.
    [pidoors.py]
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2026-04-05 v0.3.2 — Door rename protection, version transition, changelog cleanup
    Add door rename with online-only enforcement: server pushes name
    change to controller via /cmd/rename, controller updates config.json
    and restarts. Offline doors cannot be renamed.
    Add version transition logic so 3.x systems see 0.x releases as
    newer (handles the version reset). Consolidated changelog into a
    clean summary. Pre-built React SPA included in release tarballs.
    [pidoors.py]
2026-04-05 Fix systemd-run unit name collision and self-detach loop
    Use timestamp-based unit names for systemd-run transient services
    to avoid "unit already loaded" errors on repeated updates. Fix
    self-detach cgroup pattern to exclude pidoors-update services so
    the script doesn't try to detach from itself.
    [pidoors.py]
2026-04-05 Clean up repo — remove PCB, migration script, update docs
    Remove pidoorspcb/ directory (untested PCB design, misleading to
    include as if production-ready). Remove v2-v3migrate.sh (obsolete).
    Add voltage level shifter warnings to Wiegand wiring docs in both
    README and INSTALLATION_GUIDE — 5V Wiegand signals can damage the
    Pi's 3.3V GPIO pins without a level shifter.
    Remove PCB reference from directory structure in README.
    [pidoors-hat-B_Cu.gbl, pidoors-hat-B_Mask.gbs, pidoors-hat-B_SilkS.gbo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]
2026-04-11 v0.3.3 — Gate mode, status LED, install fixes
    Add gate mode for doors with rolling/sliding gates: 3 configurable
    inputs (open/stop/close physical buttons), 3 configurable outputs
    (open/stop/close relays), per-pin GPIO assignment, hi/lo polarity,
    hold duration, debounce, triple-tap window, pull-resistor type.
    Triple-tap on physical inputs enters hold state. Gate state machine
    tracks current state (idle/opening/closing/stopped/open/closed) and
    held flag. Web UI shows gate state badge and dedicated open/close/
    stop/hold/release buttons. Card scans on a gate trigger the open
    output. Master card 3-scan = hold open, 1-scan = release.
    Add universal status LED feature (separate from gate mode)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
    [pidoors.py]
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2026-04-11 v0.3.5 — Fix rename corruption and update loop
    Rename handler now:
    - Updates in-memory zone global immediately (no longer relies on
    restart to pick up the new name)
    - Refuses to proceed if the old zone key is missing from
    config.json (prevents creating broken empty entries)
    - No-ops on same-name renames
    - Uses sudo -n for restart so failed sudoers don't hang
    Sudoers adds systemctl restart pidoors so rename can actually
    restart the service to reinitialize GPIO/listener.
    Update script:
    - Reads zone from zone.json (source of truth) instead of CLI arg
    - Refuses to create phantom empty zone entries if config is wrong
    - Guards against double self-update via PIDOORS_SELF_UPDATED env var
    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
    [pidoors.py]
2026-04-11 v0.3.7 — Actionable gate command errors + live state sync
    Gate commands now return a (ok, reason) tuple from the controller
    so the web UI can display specific error messages instead of a
    generic "refused" fallback:
    - 'held' → "Gate is held. Release the hold first."
    - 'no_output_configured' → "No output pin is configured for this
    direction. Open the door settings and assign a pin..."
    - 'already_running' → "Gate is already opening/closing."
    Server-side polling (poll_all_door_status and ping_controller)
    now reads gate_state and gate_held from the controller's /ping
    response and writes them to the DB. This means the Held badge
    and current gate state update on the next 5-second UI pol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
    [pidoors.py]
2026-04-11 v0.3.8 — Auto-close, dashboard gate controls, session fix
    Gate auto-close:
    - New optional clearance sensor input (4th gate input) for beam-break,
    IR, or laser sensors at the gate opening
    - Configurable polarity and "active means clear/blocked" logic
    - New auto_close section in gate config: enable + delay (1-3600s)
    - Mandatory safety: auto-close requires a clearance sensor — UI greys
    out the toggle, API rejects enable requests, controller refuses to
    fire if sensor is missing or path is blocked
    - Auto-close fires after gate transitions to 'open' state if all
    conditions are met
    - Sensor breaking cancels the timer; clearing restarts it
    - Any manual command (open/close/stop/hold) canc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
    [pidoors.py]
2026-04-15 v0.3.9 — React 19 + Vite 6 migration + Python requirements safety net
    Major dependency migration:
    - React 18.3.1 → 19.0.0
    - react-dom 18.3.1 → 19.0.0
    - @types/react 18.3.28 → 19.x
    - @types/react-dom 18.3.7 → 19.x
    - @vitejs/plugin-react 4.7.0 → 5.x (React 19 compat)
    - Vite 5.4.21 → 6.x (Node 18+ required, Pi has 20.19.2)
    - @tanstack/react-query 5.60 → 5.99
    Build verified clean on Pi hardware: zero TypeScript errors, zero
    npm audit vulnerabilities, SPA bundle produces correct output.
    Python dependency management:
    - New pidoors/requirements.txt (source of truth for controller deps)
    - pidoors-update.sh now runs pip install -r requirements.txt on
    every update — future new Py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
    [pidoors.py]
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

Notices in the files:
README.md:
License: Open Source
